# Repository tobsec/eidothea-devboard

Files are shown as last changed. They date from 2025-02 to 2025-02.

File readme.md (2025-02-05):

# EIDOTHEA DEVBOARD

The **Eidothea DevBoard** is designed for testing and development, compatible with the [Eidothea Board](https://github.com/tobsec/eidothea). It can be used both on a test bench and within an engine setup.

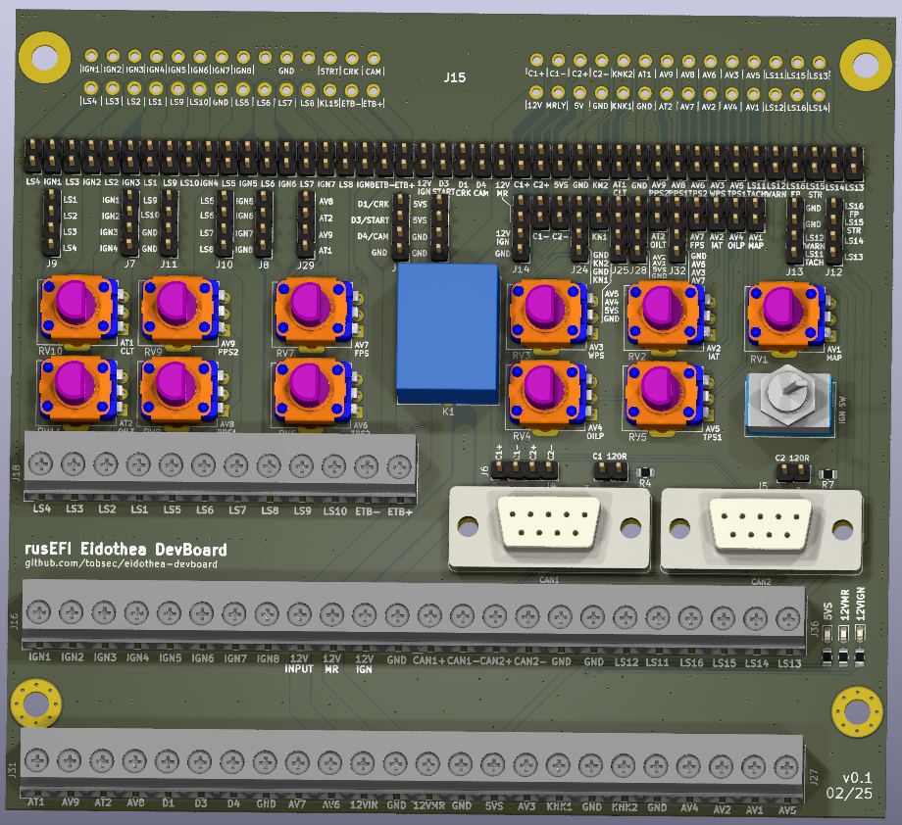
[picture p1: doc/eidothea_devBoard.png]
Eidothea DevBoard


## Hardware Features

### Connectors

- **Sicma 56 Connector**: A weatherproof connector available on [AliExpress](https://aliexpress.com/item/32857771975.html).
- **Connector with 20cm Wiring Harness**: This is available for connecting to the Eidothea Board, also on [AliExpress](https://aliexpress.com/item/1005007332736311.html).

### Connectivity

- **2x CAN Bus Ports**: Available via SubD9 connectors (120Ω selectable).
- **Engine Connections**: All engine connections can be interrupted or disconnected as needed.
- **Pin Headers**: All signals are available on pin headers for easy probing or signal injection.

### Features

- **Ignition Toggle Switch**: For bench testing purposes.
- **Main Power Relay**: For controlling power during testing.
- **Analog Channel Emulation**: Analog channels can be emulated using potentiometers for simulation.

## Pinout
| No. | Pin | Description | IN / OUT | Function |
|-----|---|---|---|---|
| 1 | IGN1 | Ignition Trigger 1 | OUT | Gate Driver IC |
| 2 | IGN2 | Ignition Trigger 2 | OUT | Gate Driver IC |
| 3 | IGN3 | Ignition Trigger 3 | OUT | Gate Driver IC |
| 4 | IGN4 | Ignition Trigger 4 | OUT | Gate Driver IC |
| 5 | IGN5 | Ignition Trigger 5 | OUT | Gate Driver IC |
| 6 | IGN6 | Ignition Trigger 6 | OUT | Gate Driver IC |
| 7 | IGN7 | Ignition Trigger 7 | OUT | Gate Driver IC |
| 8 | IGN8 | Ignition Trigger 8 | OUT | Gate Driver IC |
| 9 | GND | GND | IN | Supply |
| 10  | GND | GND | IN | Supply |
| 11  | GND | GND | IN | Supply |
| 12  | DIGITAL_3 | Start Switch/Button Signal | IN | Digital In 12V |
| 13  | DIGITAL_VR_1 | Crank Sensor | IN | HALL / VR In |
| 14  | DIGITAL_VR_4 | Cam Sensor | IN | HALL / VR In |
| 15  | LS4 | Injector 4 | OUT | Low Side Switch |
| 16  | LS3 | Injector 3 | OUT | Low Side Switch |
| 17  | LS2 | Injector 2 | OUT | Low Side Switch |
| 18  | LS1 | Injector 1 | OUT | Low Side Switch |
| 19  | LS9 | Spare (e.g. Boost Control) | OUT | Low Side Switch |
| 20  | LS10 | Main Relay Drive | OUT | Low Side Switch |
| 21  | GND | Knock Sensor 2 - | IN | Knock Sensing |
| 22  | LS5 | Injector 5 | OUT | Low Side Switch |
| 23  | LS6 | Injector 6 | OUT | Low Side Switch |
| 24  | LS7 | Injector 7 | OUT | Low Side Switch |
| 25  | LS8 | Injector 8 | OUT | Low Side Switch |
| 26  | 12V_RAW (+ DIGITAL_2) | Ignition (KL15) | IN | Supply |
| 27  | ETB1- | ETB M- / Idle Stepper A2 | OUT | H Bridge (opt. Stepper) |
| 28  | ETB1+ | ETB M+ / Idle Stepper A1 | OUT | H Bridge (opt. Stepper) |
| 29  | CAN+ | CAN1 H | IN / OUT | O2 Sensor CAN (500kbps) |
| 30  | CAN- | CAN1 L | IN / OUT | O2 Sensor CAN (500kbps) |
| 31  | CAN2+ | CAN2 H | IN / OUT | NMEA2000 CAN (250kbps)  |
| 32  | CAN2- | CAN2 L | IN / OUT | NMEA2000 CAN (250kbps)  |
| 33  | KNOCK_2 | Knock Sensor 2 + | IN | Knock Sensing |
| 34  | AT1 | Water Temperature Sensor | IN | Analog Temp |
| 35  | AV9 | PPS2 (Idle Stepper B2) | IN (OUT) | Analog  (opt. Stepper)  |
| 36  | AV8 | PPS1 (Idle Stepper B1) | IN (OUT) | Analog  (opt. Stepper)  |
| 37  | AV6 | ETB TPS2 | IN | Analog Voltage |
| 38  | AV3 | Water Pressure Sensor | IN | Analog Voltage |
| 39  | AV5 | ETB TPS1 | IN | Analog Voltage |
| 40  | LS11_F | Tacho Out | OUT | Low Side + PullUp |
| 41  | LS15_F | Starter Relay Drive | OUT | Low Side Switch |
| 42  | LS13_F | ~Main Relay Drive~ Spare | OUT | Low Side Switch |
| 43  | 12V_MR | Power (from Main Relay) | IN | Supply |
| 44  | 12V_MR | Power (from Main Relay) | IN | Supply |
| 45  | 5V_SENSOR_1 | Sensor Supply 5V | OUT | Analog Supply 150mA |
| 46  | GND | Sensor GND | OUT | Analog GND |
| 47  | KNOCK_1 | Knock Sensor 1 + | IN | Knock Sensing |
| 48  | GND | Knock Sensor 1 - | IN | Knock Sensing |
| 49  | AT2 | Oil Temperature Sensor | IN | Analog Temp |
| 50  | AV7 | Fuel Pressure Sensor | IN | Analog Voltage |
| 51  | AV2 | IAT Sensor | IN | Analog ~Voltage~ Temp |
| 52  | AV4 | Oil Pressure Sensor | IN | Analog Voltage |
| 53  | AV1 | MAP Sensor | IN | Analog Voltage |
| 54  | LS12_F | Audio Warning Horn / MIL | OUT | Low Side Switch |
| 55  | LS16_F | Fuel Pump Relay Drive | OUT | Low Side Switch |
| 56  | LS14_F | Spare (e.g. Boost Control) | OUT | Low Side Switch |

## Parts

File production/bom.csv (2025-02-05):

Designator | Footprint | Quantity | Value | LCSC Part #
D3, D4, D8 | 0603 | 3 | GREEN | C72043
J1, J10, J11, J12, J13, J14, J24, J25, J28, J29, J32, J34, J6, J7, J8, J9 | PinHeader_1x04_P2.54mm_Vertical | 16 | Conn_01x01 | N/A
J16, J18, J27, J31, J36 | TerminalBlock_RND_205-00011_1x12_P5.00mm_Horizontal | 5 | Screw_Terminal_01x04
J4, J5 | DSUB-9_Female_Vertical_P2.77x2.84mm_MountingHoles | 2 | DE9_Plug_MountingHoles
JP1 | SolderJumper-2_P1.3mm_Open_RoundedPad1.0x1.5mm | 1 | Jumper_2_Bridged
JP10, JP11, JP13, JP14, JP15, JP16, JP17, JP18, JP19, JP2, JP20, JP21, JP22, JP23, JP24, JP25, JP26, JP27, JP28, JP29, JP3, JP30, JP31, JP32, JP33, JP35, JP36, JP37, JP38, JP39, JP4, JP40, JP41, JP42, JP43, JP44, JP45, JP46, JP47, JP48, JP49, JP5, JP50, JP52, JP53, JP54, JP55, JP56, JP57, JP6, JP7, JP8, JP9 | PinHeader_1x02_P2.54mm_Vertical | 53 | Jumper_2_Bridged
K1 | Relay_SPDT_SANYOU_SRD_Series_Form_C | 1 | SANYOU_SRD_Form_C
R3, R5 | 0805 | 2 | 2k7 | C138017
R4, R7 | 0805 | 2 | R_Small
R6 | 0805 | 1 | 1k | C11702
RV1, RV10, RV11, RV2, RV3, RV4, RV5, RV6, RV7, RV8, RV9 | Potentiometer_Alps_RK09K_Single_Vertical | 11 | R_Potentiometer_Small
SW1 | SW_Toggle_Blue_wSlots | 1 | SW_SPDT

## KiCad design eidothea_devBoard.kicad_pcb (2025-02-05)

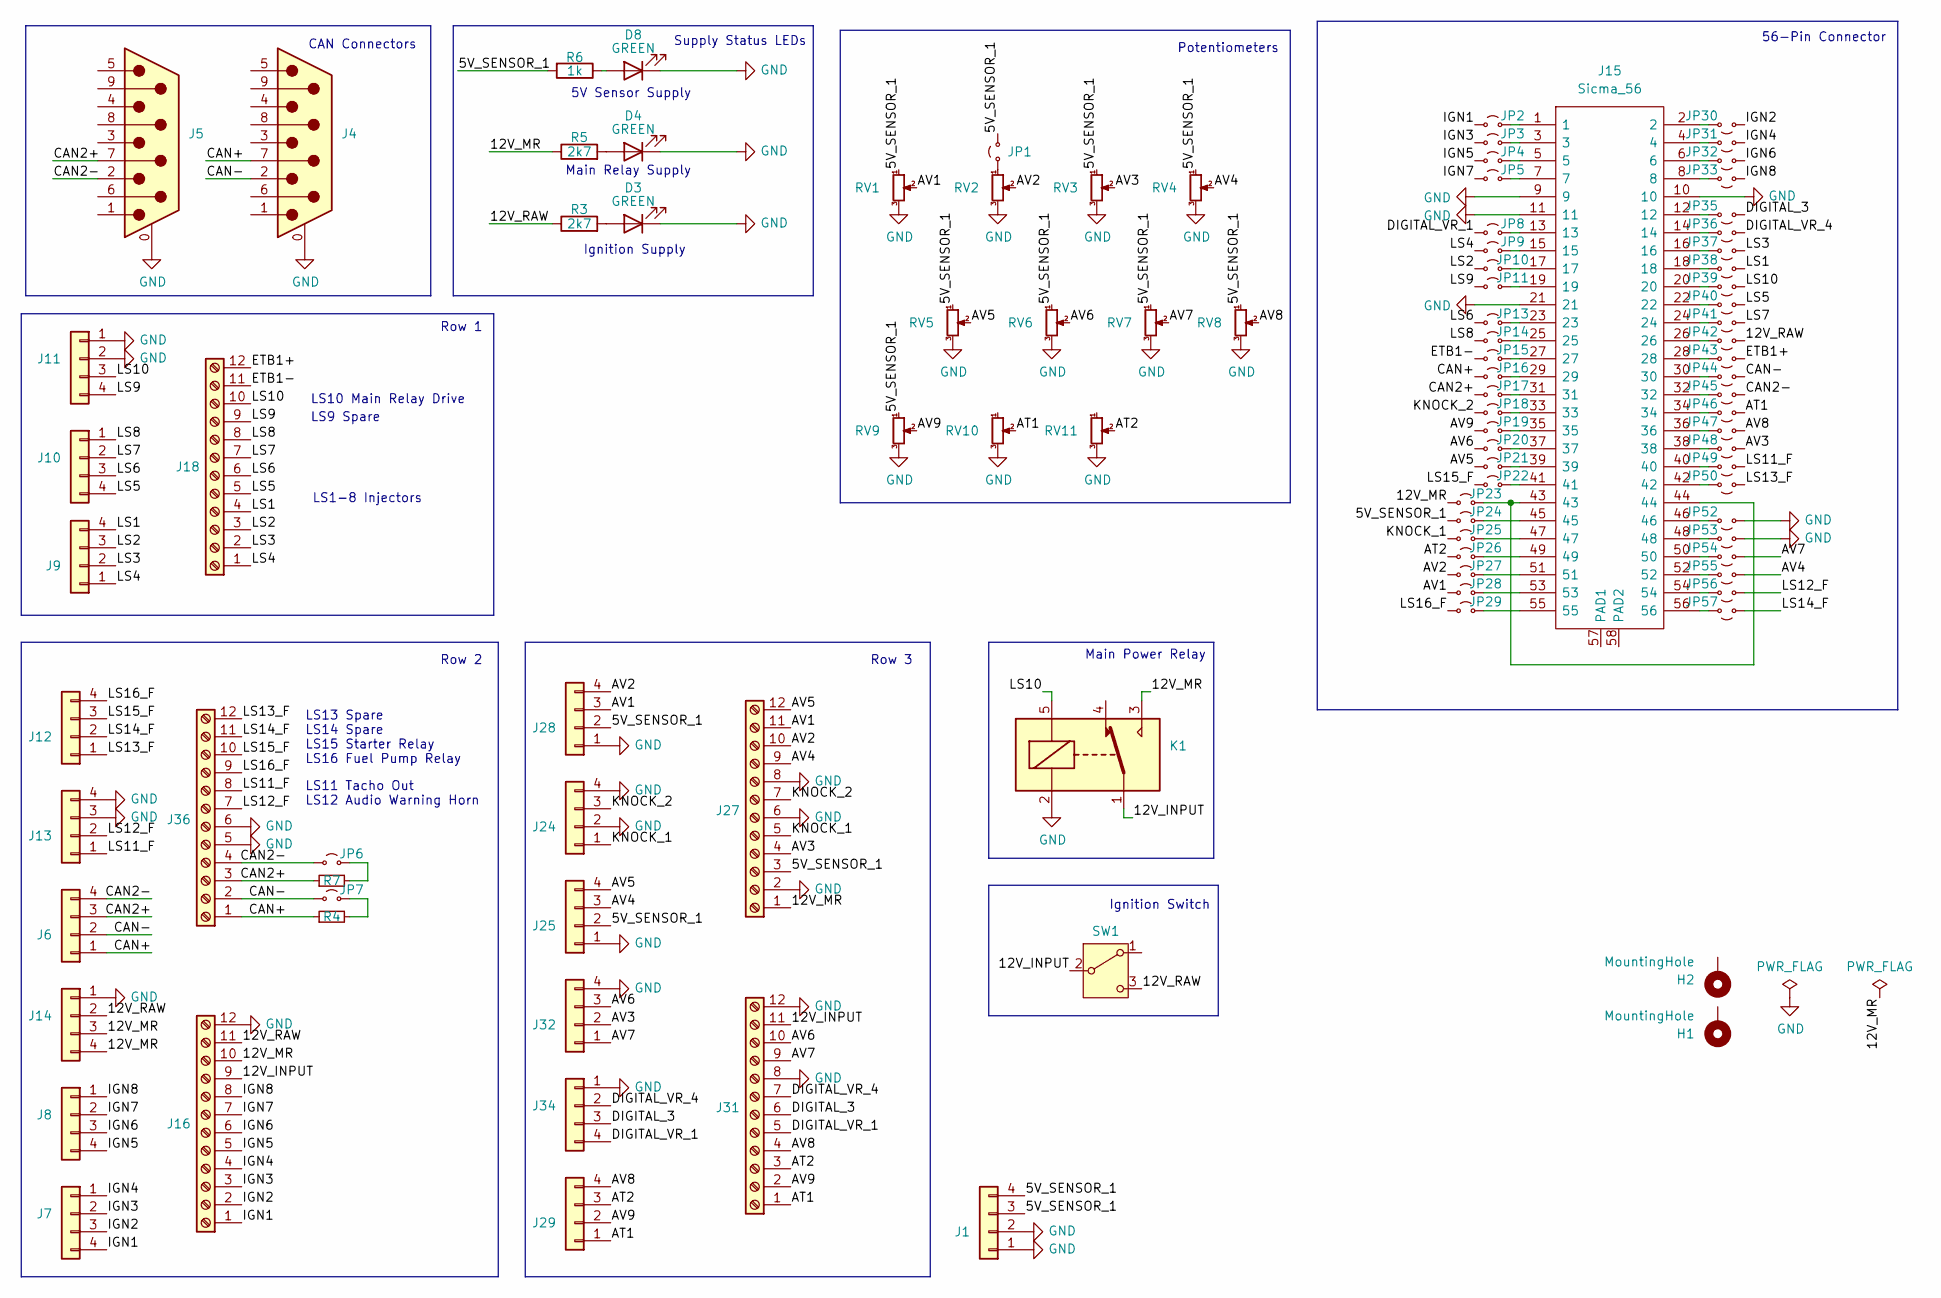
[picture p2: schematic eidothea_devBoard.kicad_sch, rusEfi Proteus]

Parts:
D3, D4, D8: GREEN; LED_0603_1608Metric; LCSC C72043
H1, H2: MountingHole; MountingHole_4mm_Pad_Via
J1, J6, J7, J8, J9, J10, J11, J12, J13, J14, J24, J25, J28, J29, J32, J34: Conn_01x01; PinHeader_1x04_P2.54mm_Vertical; LCSC N/A
J4, J5: DE9_Plug_MountingHoles; DSUB-9_Female_Vertical_P2.77x2.84mm_MountingHoles
J15: Sicma_56; Manufacturer_Part_Number 211PL562L0011
J16, J18, J27, J31, J36: Screw_Terminal_01x04; TerminalBlock_RND_205-00011_1x12_P5.00mm_Horizontal
JP1: Jumper_2_Bridged; SolderJumper-2_P1.3mm_Open_RoundedPad1.0x1.5mm
JP2, JP3, JP4, JP5, JP6, JP7, JP8, JP9, JP10, JP11, JP13, JP14, JP15, JP16, JP17, JP18, JP19, JP20, JP21, JP22, JP23, JP24, JP25, JP26, JP27, JP28, JP29, JP30, JP31, JP32, JP33, JP35, JP36, JP37, JP38, JP39, JP40, JP41, JP42, JP43, JP44, JP45, JP46, JP47, JP48, JP49, JP50, JP52, JP53, JP54, JP55, JP56, JP57: Jumper_2_Bridged; PinHeader_1x02_P2.54mm_Vertical
K1: SANYOU_SRD_Form_C; Relay_SPDT_SANYOU_SRD_Series_Form_C
R3, R5: 2k7; R_0805_2012Metric; LCSC C138017
R4, R7: R_Small; R_0805_2012Metric
R6: 1k; R_0805_2012Metric; LCSC C11702
RV1, RV2, RV3, RV4, RV5, RV6, RV7, RV8, RV9, RV10, RV11: R_Potentiometer_Small; Potentiometer_Alps_RK09K_Single_Vertical
SW1: SW_SPDT; SW_Toggle_Blue_wSlots

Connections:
/5V_SENSOR_1: J1.3, J1.4, J25.2, J27.3, J28.2, JP1.2 (B), JP24.1 (A), R6.2, RV1.1, RV3.1, RV4.1, RV5.1, RV6.1, RV7.1, RV8.1, RV9.1
/12V_INPUT: J16.9, J31.11, K1.1, SW1.2 (B)
/12V_MR: J14.3, J14.4, J16.10, J27.1, JP23.1 (A), K1.3, R5.1
/12V_RAW: J14.2, J16.11, JP42.1 (A), R3.1, SW1.3 (C)
/AT1: J29.1, J31.1, JP46.1 (A), RV10.2
/AT2: J29.3, J31.3, JP26.1 (A), RV11.2
/AV1: J27.11, J28.3, JP28.1 (A), RV1.2
/AV2: J27.10, J28.4, JP27.1 (A), RV2.2
/AV3: J27.4, J32.2, JP48.1 (A), RV3.2
/AV4: J25.3, J27.9, JP55.1 (A), RV4.2
/AV5: J25.4, J27.12, JP21.1 (A), RV5.2
/AV6: J31.10, J32.3, JP20.1 (A), RV6.2
/AV7: J31.9, J32.1, JP54.1 (A), RV7.2
/AV8: J29.4, J31.4, JP47.1 (A), RV8.2
/AV9: J29.2, J31.2, JP19.1 (A), RV9.2
/CAN2+: J5.7, J6.3, J36.3, JP17.1 (A), R7.1
/CAN2-: J5.2, J6.4, J36.4, JP6.1 (A), JP45.1 (A)
/CAN+: J4.7, J6.1, J36.1, JP16.1 (A), R4.1
/CAN-: J4.2, J6.2, J36.2, JP7.1 (A), JP44.1 (A)
/DIGITAL_3: J31.6, J34.3, JP35.1 (A)
/DIGITAL_VR_1: J31.5, J34.4, JP8.1 (A)
/DIGITAL_VR_4: J31.7, J34.2, JP36.1 (A)
/ETB1+: J18.12, JP43.1 (A)
/ETB1-: J18.11, JP15.1 (A)
/IGN1: J7.4, J16.1, JP2.1 (A)
/IGN2: J7.3, J16.2, JP30.1 (A)
/IGN3: J7.2, J16.3, JP3.1 (A)
/IGN4: J7.1, J16.4, JP31.1 (A)
/IGN5: J8.4, J16.5, JP4.1 (A)
/IGN6: J8.3, J16.6, JP32.1 (A)
/IGN7: J8.2, J16.7, JP5.1 (A)
/IGN8: J8.1, J16.8, JP33.1 (A)
/KNOCK_1: J24.1, J27.5, JP25.1 (A)
/KNOCK_2: J24.3, J27.7, JP18.1 (A)
/LS1: J9.4, J18.4, JP38.1 (A)
/LS2: J9.3, J18.3, JP10.1 (A)
/LS3: J9.2, J18.2, JP37.1 (A)
/LS4: J9.1, J18.1, JP9.1 (A)
/LS5: J10.4, J18.5, JP40.1 (A)
/LS6: J10.3, J18.6, JP13.1 (A)
/LS7: J10.2, J18.7, JP41.1 (A)
/LS8: J10.1, J18.8, JP14.1 (A)
/LS9: J11.4, J18.9, JP11.1 (A)
/LS10: J11.3, J18.10, JP39.1 (A), K1.5
/LS11_F: J13.1, J36.8, JP49.1 (A)
/LS12_F: J13.2, J36.7, JP56.1 (A)
/LS13_F: J12.1, J36.12, JP50.1 (A)
/LS14_F: J12.2, J36.11, JP57.1 (A)
/LS15_F: J12.3, J36.10, JP22.1 (A)
/LS16_F: J12.4, J36.9, JP29.1 (A)
GND: D3.1 (K), D4.1 (K), D8.1 (K), J1.1, J1.2, J4.0 (PAD), J5.0 (PAD), J11.1, J11.2, J13.3, J13.4, J14.1, J15.9, J15.10, J15.11, J15.21, J16.12, J24.2, J24.4, J25.1, J27.2, J27.6, J27.8, J28.1, J31.8, J31.12, J32.4, J34.1, J36.5, J36.6, JP52.1 (A), JP53.1 (A), K1.2, RV1.3, RV2.3, RV3.3, RV4.3, RV5.3, RV6.3, RV7.3, RV8.3, RV9.3, RV10.3, RV11.3
unnamed: D3.2 (A), R3.2
unnamed: D4.2 (A), R5.2
unnamed: D8.2 (A), R6.1
unnamed: JP1.1 (A), RV2.1
unnamed: J15.1, JP2.2 (B)
unnamed: J15.3, JP3.2 (B)
unnamed: J15.5, JP4.2 (B)
unnamed: J15.7, JP5.2 (B)
unnamed: JP6.2 (B), R7.2
unnamed: JP7.2 (B), R4.2
unnamed: J15.13, JP8.2 (B)
unnamed: J15.15, JP9.2 (B)
unnamed: J15.17, JP10.2 (B)
unnamed: J15.19, JP11.2 (B)
unnamed: J15.23, JP13.2 (B)
unnamed: J15.25, JP14.2 (B)
unnamed: J15.27, JP15.2 (B)
unnamed: J15.29, JP16.2 (B)
unnamed: J15.31, JP17.2 (B)
unnamed: J15.33, JP18.2 (B)
unnamed: J15.35, JP19.2 (B)
unnamed: J15.37, JP20.2 (B)
unnamed: J15.39, JP21.2 (B)
unnamed: J15.41, JP22.2 (B)
unnamed: J15.43, J15.44, JP23.2 (B)
unnamed: J15.45, JP24.2 (B)
unnamed: J15.47, JP25.2 (B)
unnamed: J15.49, JP26.2 (B)
unnamed: J15.51, JP27.2 (B)
unnamed: J15.53, JP28.2 (B)
unnamed: J15.55, JP29.2 (B)
unnamed: J15.2, JP30.2 (B)
unnamed: J15.4, JP31.2 (B)
unnamed: J15.6, JP32.2 (B)
unnamed: J15.8, JP33.2 (B)
unnamed: J15.12, JP35.2 (B)
unnamed: J15.14, JP36.2 (B)
unnamed: J15.16, JP37.2 (B)
unnamed: J15.18, JP38.2 (B)
unnamed: J15.20, JP39.2 (B)
unnamed: J15.22, JP40.2 (B)
unnamed: J15.24, JP41.2 (B)
unnamed: J15.26, JP42.2 (B)
unnamed: J15.28, JP43.2 (B)
unnamed: J15.30, JP44.2 (B)
unnamed: J15.32, JP45.2 (B)
unnamed: J15.34, JP46.2 (B)
unnamed: J15.36, JP47.2 (B)
unnamed: J15.38, JP48.2 (B)
unnamed: J15.40, JP49.2 (B)
unnamed: J15.42, JP50.2 (B)
unnamed: J15.46, JP52.2 (B)
unnamed: J15.48, JP53.2 (B)
unnamed: J15.50, JP54.2 (B)
unnamed: J15.52, JP55.2 (B)
unnamed: J15.54, JP56.2 (B)
unnamed: J15.56, JP57.2 (B)

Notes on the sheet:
Ignition Switch
LS9 Spare
LS1-8 Injectors
Supply Status LEDs
Row 1
Main Power Relay
56-Pin Connector
CAN Connectors
LS10 Main Relay Drive
LS13 Spare LS14 Spare LS15 Starter Relay LS16 Fuel Pump Relay
Main Relay Supply
Row 2
LS11 Tacho Out LS12 Audio Warning Horn
Potentiometers
Row 3
Ignition Supply
5V Sensor Supply

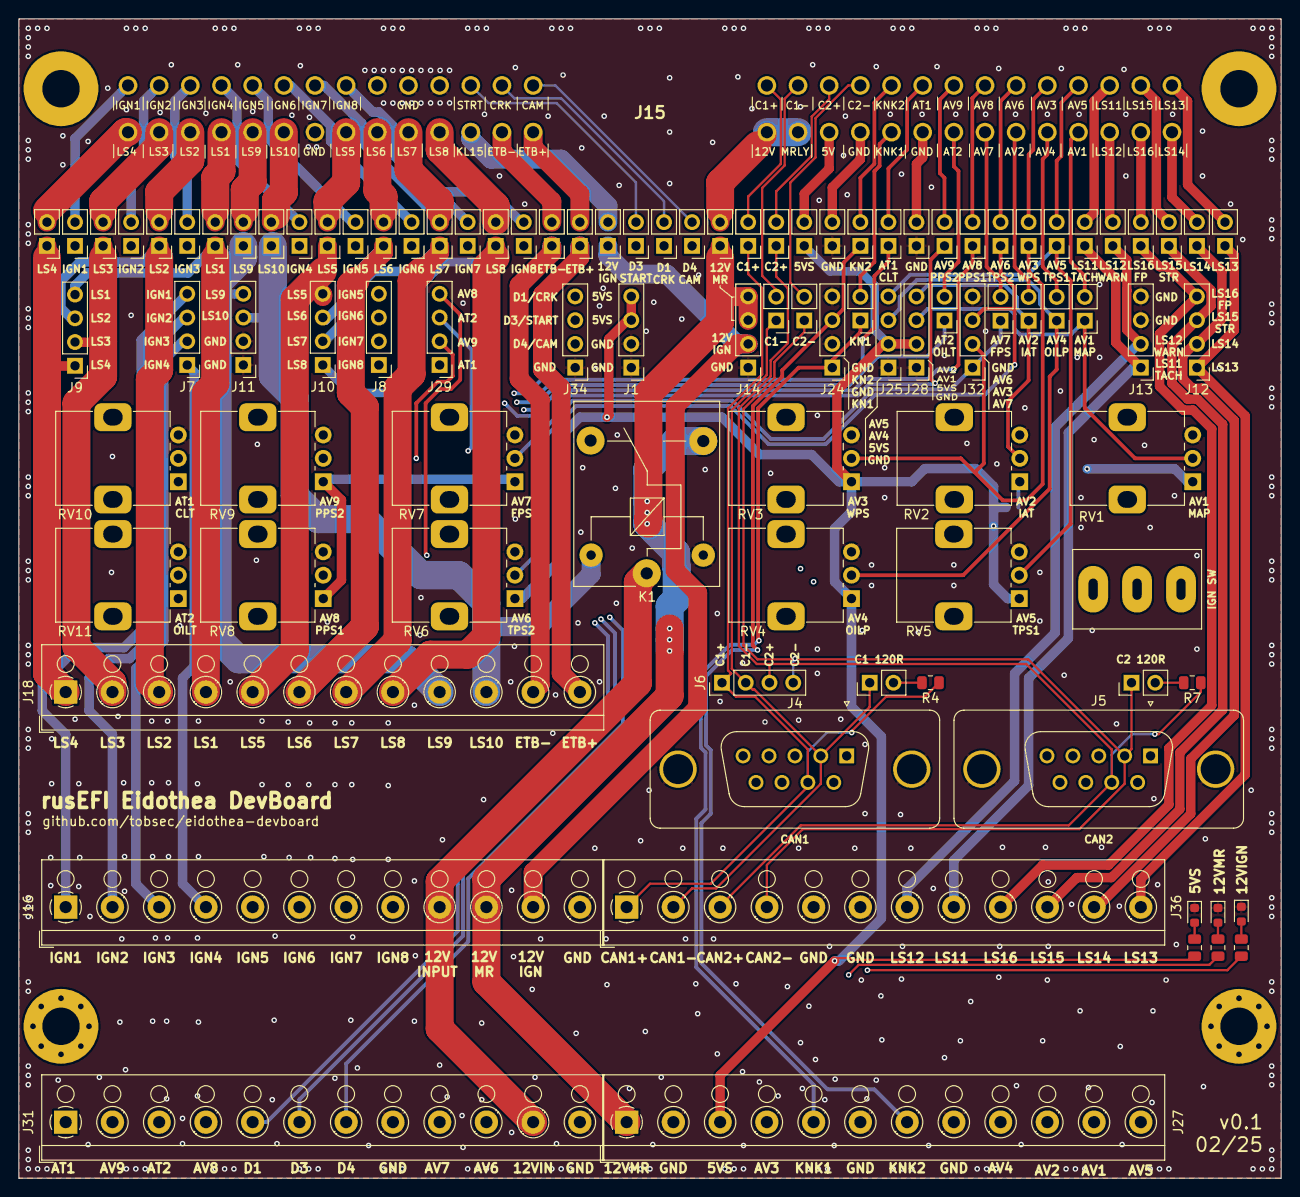
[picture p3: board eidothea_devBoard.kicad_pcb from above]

Board: 4 copper layers, 135.0 x 124.0 mm, 101 parts (1 on the bottom side), 108 nets.
